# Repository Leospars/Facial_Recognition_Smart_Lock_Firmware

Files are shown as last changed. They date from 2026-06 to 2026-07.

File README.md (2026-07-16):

# JUPY Security Lock — Firmware

This repository contains the ESP32 firmware for a Facial Recognition door lock which integrates with a K230D vision module and the JUPY Locks React Native app (separate repo). The firmware manages local PIN entry, face unlock via the K230D, notifications via Firebase Cloud Messaging (FCM), and remote control via MQTT.

**Key Features**

- Face unlock integration: wakes and reads K230D UART JSON responses.
- Local passcode entry via a small TFT touchscreen keypad.
- Doorbell and remote unlock using MQTT and FCM notifications.
- On-device settings via a local REST API and secure pin-based auth.
- Battery monitoring and power-saving modes for long-life operation.

**Hardware & Pins**

- Hardware Schematic at [JUPY Lock Firmware.kicad_sch](./jupy_lock_schematic.kicad_sch)
- ESP32 (WROOM-series)
- K230D power: `K230D_PWR_PIN`
- PIR motion sensor: `PIR_PIN`
- Lock (solenoid) control: `LOCK_PIN`
- Battery ADC: `BATTERY_PIN`
- TFT / Touch pins: configured for included `TFT_eSPI` usage; see `src/main.cpp` for mapping (`TFT_MISO`, `TFT_MOSI`, `TFT_SCLK`, `TFT_CS`, `TFT_DC`).

Pin constants are defined at the top of `src/main.cpp`.

Dependencies (PlatformIO)

- Arduino Framework for ESP32
- WiFi, WiFiClientSecure
- PubSubClient (MQTT)
- ArduinoJson
- Preferences (for persistent settings)
- TFT_eSPI (display + touch)

### Setup

**Build and Flash**

1. Install PlatformIO in VS Code.
2. Open this project.
3. Configure `platformio.ini` for your board and upload.

**Configure TFT_eSPI**

Navigate to the dependency folder .pio/[board]/User_Setup.h uncomment your board and edit the following; optionally in User_Setup_Select.h select your board

```c++
// Example for ESP32 S3 Setup
// For ESP32 Dev board (only tested with ILI9341 display)
// The hardware SPI can be mapped to any pins

#define TFT_MISO 37
#define TFT_MOSI 35
#define TFT_SCLK 36
#define TFT_CS   39  // Chip select control pin
#define TFT_DC   38  // Data Command control pin
//#define TFT_RST   4  // Reset pin (could connect to RST pin)
#define TFT_RST  -1  // Set TFT_RST to -1 if display RESET is connected to ESP32 board RST
```

### Operation

**Configuration & Provisioning**

- Settings and secrets are stored in the ESP32 `Preferences` namespace (`my-settings`).
- On first boot (no saved Wi‑Fi), a BLE / Matter-style provisioning payload is expected to supply `wifi-ssid`, `wifi-pwd`, `user-id`, `lock-name`, and `owner-name`. In the example code a placeholder payload is used — replace with your BLE/Matter provisioning flow.
- Set your FCM server key in the `fcm_key` constant to enable push notifications.

**Network & Cloud Interfaces**

- MQTT broker: default `broker.hivemq.com` (change in `src/main.cpp`).
- MQTT topics used:
  - Subscribe: `lock/commands/<USER_ID>` — receives JSON commands (e.g. `{ "cmd": "unlock" }`).
  - Publish (logs): `lock/logs/<USER_ID>` (when MQTT session active).
- FCM notifications: posts to `fcm.googleapis.com` using the configured server key. Payloads send notifications to topic `/topics/<USER_ID>/all`.

**Local REST API (HTTP on ESP32)**

- `POST /unlock` — Body: JSON { "pin": "1234", "name": "Caller" }. Verifies stored PIN and pulses the lock.
- `PATCH /update-settings` — Body: JSON with `name`, `pin`, and `settings` object. Requires auth with correct owner name + PIN. Settings include: `vid-quality`,  `call-timeout`, `snippet-time`, `share-analytics`.

**Behavior Notes**

- K230D wake: PIR or remote commands call `wakeK230D()` which toggles the K230D power pin and logs activity. K230D is auto-powered down after ~3s of no face detection (configurable in code).
- Initailization: BLE server for wifi commissioning and lock setup
- Auth lockout: 3 failed auth attempts set an authorization timeout (`AUTH_DISABLE_TIME`) — after that period authFail resets.
- Intruder handling: repeated unknown-face detections increment an `intruder` counter and can cause a longer timeout.
- Battery monitoring: periodic ADC reads map to battery percentages and trigger FCM notifications for low battery states.

**Power Saving**

- Wi‑Fi modem sleep is enabled via `esp_wifi_set_ps(WIFI_PS_MIN_MODEM)` and station listen interval is adjusted to reduce power consumption.
- BLE is disabled after provisioning to save power.
- MQTT is disable during inactivity and re-enables after timeout
- Assign deep sleep wake up triggers

**Customizing & Extending**

- Replace the placeholder provisioning with Matter or your BLE service to provision Wi‑Fi and owner details.
- Replace `fcm_key` and `mqtt_server` with your production credentials.
- Adjust pin constants and voltage divider math in `monitorBattery()` to match your hardware.

**Security and Privacy**

- Use external rest api to trigger fcm to avoid committing `fcm_key` to public repos.
- Ensure MQTT broker is configured with TLS/auth if used in production.
- Consider setting up HTTPS/TLS 3.1 for local rest api in production.
- Use cryptographic keys and methods for authorizing commands and changing settings in production.

### Known Issues

- The footprint of the ESP32-S3 module is slightly smaller than the actual device in the [schematic file](./jupy_lock_schematic.kicad_sch). A perfboard was used instead to connect the pins with dupont jumper wires. 

### Future Implementations

- Encypt ble server uuid and name for qr code scan
- Implement reset lock when on board button is held for set time 3s

### Project Images

- Breadboard Assembly
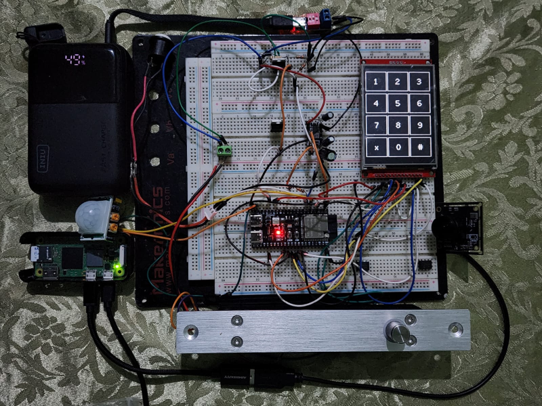
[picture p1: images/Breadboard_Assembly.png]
Breadboard Assembly Image


- Enclosed Door Lock
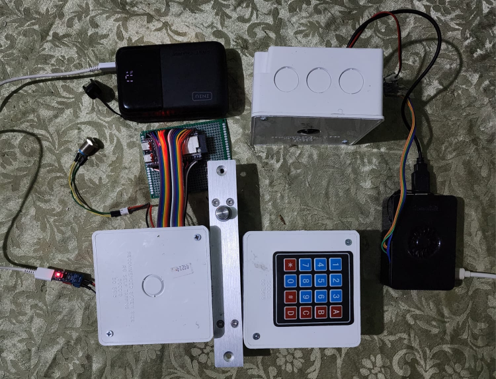
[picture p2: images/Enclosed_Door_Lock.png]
Enclosed Door Lock Image


- Proposed 3D Model
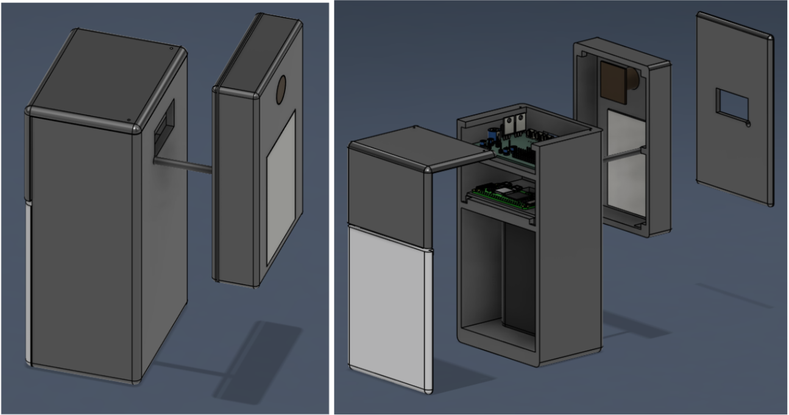
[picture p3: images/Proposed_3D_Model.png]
Proposed 3D Model Image


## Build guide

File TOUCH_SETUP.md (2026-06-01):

# Touch Screen Setup Guide

This guide explains how to set up and configure the touch screen functionality for the JUPY Smart Lock project.

## Hardware Requirements

- ILI9341 TFT Display with XPT2046 Touch Controller
- ESP32-S3 Development Board
- Proper wiring connections as per the schematic

## Pin Configuration

The touch screen uses the following pins (defined in `include/User_Setup.h`):

- **TOUCH_CS**: GPIO 40 - Touch controller chip select
- **T_IRQ**: GPIO 21 - Touch interrupt pin
- **TFT SPI Pins**:
  - MOSI: GPIO 11
  - MISO: GPIO 13
  - SCLK: GPIO 12
  - TFT_CS: GPIO 10
  - TFT_DC: GPIO 9
  - TFT_RST: -1 (connected to ESP32 RST)

## Software Configuration

### 1. Library Dependencies

The following libraries are required and configured in `platformio.ini`:

- `bodmer/TFT_eSPI@^2.5.43` - TFT display library
- `paulstoffregen/XPT2046_Touchscreen@^1.4.0` - Touch controller library

### 2. TFT_eSPI Configuration

A custom `User_Setup.h` file is provided in the `include/` directory with the correct pin configuration for ESP32-S3 and ILI9341 display.

Key settings:
- Driver: `ILI9341_DRIVER`
- SPI Frequency: 27MHz for display, 2.5MHz for touch
- Touch enabled with TOUCH_CS and T_IRQ pins

### 3. Touch Calibration

The touch screen requires calibration to map touch coordinates to display coordinates.

#### Automatic Calibration
- Uncomment `// touch_calibrate();` in `setup()` function
- Upload and run the code
- Follow on-screen instructions to touch the corners
- Calibration data will be printed to Serial monitor
- Copy the calibration array and update the code

#### Manual Calibration Data
Default calibration data is provided:
```cpp
uint16_t calData[5] = {1, 65024, 8, 64506, 5};
tft.setTouch(calData);
```

## Code Integration

### Touch Handling

The touch functionality is implemented in the `handleTouch()` function:

- Detects touch state changes
- Maps touch coordinates to keypad grid (4x3 layout)
- Processes key presses through `processKeyPress()`

### Keypad Layout

The touch screen implements a 4x3 keypad:
```
1 2 3
4 5 6
7 8 9
x 0 #
```

Where:
- `x`: Clear
- `0`: Number 0
- `#`: Enter/Submit

## Troubleshooting

### Common Issues

1. **Ghost Touches / (0,0) Coordinates**
   - Check TOUCH_CS pin connection
   - Verify T_IRQ pin connection
   - Ensure stable 3.3V power to touch controller
   - Check for SPI bus conflicts

2. **Inconsistent Touch Response**
   - Reduce SPI frequency in User_Setup.h
   - Check for electrical noise
   - Verify touch panel is properly seated

3. **Wrong Coordinates**
   - Run touch calibration
   - Update calibration data in code
   - Check display rotation setting

### Diagnostic Steps

1. Run the `touch_diagnostic.ino` sketch from the `tests/` directory
2. Check Serial output for touch events
3. Verify pin connections with multimeter
4. Test SPI communication

### Hardware Checks

- **Connections**: Ensure all SPI lines and control pins are securely connected
- **Power**: Verify 3.3V supply to touch controller
- **Ground**: Check for proper ground connections
- **Damage**: Inspect touch overlay for physical damage

## Testing

After setup:

1. Upload the code to ESP32-S3
2. Open Serial monitor
3. Touch the screen and observe coordinate output
4. Test keypad functionality by touching number areas
5. Verify PIN entry works

## References

- [TFT_eSPI Library Documentation](https://github.com/Bodmer/TFT_eSPI)
- [XPT2046 Touchscreen Library](https://github.com/PaulStoffregen/XPT2046_Touchscreen)
- [ILI9341 + XPT2046 Troubleshooting Guide](./tests/touch_troubleshooting_guide.md)

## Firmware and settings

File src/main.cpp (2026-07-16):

#include <Arduino.h>
#include <ArduinoJson.h>
#include <FastLED.h>
#include <HTTPClient.h>
#include <Preferences.h>
#include <PubSubClient.h>
#include <SPI.h>
#include <TFT_eSPI.h>
#include <WebServer.h>
#include <WiFi.h>
#include <WiFiClientSecure.h>
#include <esp_sntp.h>
#include <esp_wifi.h>
#include <time.h>

#include "ble_server.h"
#include "esp_bt.h"
#include <Keypad.h>

// --- Pins (As specified) ---
#define LOCK_PIN 7
#define SBC_PWR_PIN 8
#define BATTERY_PIN 6
#define PIR_PIN 4
#define BUTTON_PIN 5
#define T_IRQ 21        // Touch Interrupt
#define TFT_LED 13      // TFT Backlight
#define RGB_LED_PIN 48  // RGB LED data pin for ESP32-S3 DevKitM
#define NUM_LEDS 1
#define BRIGHTNESS 40
CRGB leds[NUM_LEDS];

// Display PINS initialized in User_Setup.h of TFT_eSPI Library

// --- Configuration & Credentials ---
#define LOCK_ID "c0ffee01-1234-4abc-9def-9876543210aa"  // Unique Lock Identifier UUIDv7
#define SIMPLE_ID "coff"                                // Simple ID (first 4 characters of LOCK_ID)
#define LOCK_MODEL "JUPY Lock Pro"                      // Lock Model
#define FIRMWARE_VERSION "v1.0"                         // Firmware version
#define PAIRING_CODE "123456"                           // Lock Pairing Code
#define RESET_PIN "01455489"               // Reset PIN for factory reset/delete lock via REST API/touch pad
#define BACKUP_PIN "01455489"              // Dynamic Backup PIN that changes after use via REST API
#define AUTH_DISABLE_TIME 30 * 60000UL     // 30 minutes
#define BATT_CHECK_TIMEOUT 5 * 60000ULL    // 5 minutes
#define COMMISSION_TIME 10 * 60000UL       // 10 minutes
#define MQTT_ACTIVE_TIMEOUT 2 * 60000UL    // 2 minutes
#define SBC_POWEROFF_DELAY 2000UL          // 2s grace period for Pi cleanup before GPIO LOW
#define SBC_MAX_RUNTIME 6 * 1000UL         // 6s max runtime for SBC before auto power-off
#define MAX_NOTIF 10                       // Max notifications to store offline
#define DEF_NOTIF_NAME "Manual Operation"  // Default notification name

// --- Remote MQTT (HiveMQ Cloud) ---
const char *mqtt_server = "72300a81dfec465f840ffafaa812a8bb.s1.eu.hivemq.cloud";
const char *mqtt_user = "jupyLock";
const char *mqtt_pwd = "jupyLock012";

// --- Local MQTT broker (Raspberry Pi 5 / jupy_bridge.local) ---
// Uses same credentials as HiveMQ for consistency (Mosquitto configured with password auth)
const char *local_mqtt_host = "jupy-bridge.local";
const uint16_t local_mqtt_port = 1883;
const char *local_mqtt_user = "jupyLock";
const char *local_mqtt_pwd = "jupyLock012";

// --- Local MQTT Topics ---
// ESP32 → Pi
#define TOPIC_SBC_CMD                                                                                                  \
  "jupy/sbc/cmd"  // Commands to SBC: on, capture_face, doorbell_chime, start_call, update_settings, commission,
                  // power_off
#define TOPIC_SETTINGS "jupy/settings"  // Full settings JSON push → Pi writes to settings.json
// Pi → ESP32
#define TOPIC_SBC_STATUS "jupy/sbc/status"  // Status responses from SBC: match, intruder, no_face, awake, error, etc.

// --- Supabase ---
const char *projectId = "ienqcmbfdobzcggkhajc";
const String api_base_endpoint = "https://" + String(projectId) + ".supabase.co/functions/v1/make-server-a213de84";
// ("http://" + String(laptop_ip) + ":3000/api/lock/register").c_str(); //local dev
const String analytics_endpoint = api_base_endpoint + "/analytics";
const String notification_endpoint = api_base_endpoint + "/event/" + LOCK_ID;
const String register_lock_endpoint = api_base_endpoint + "/locks/register";
const String lock_endpoint = api_base_endpoint + "/lock/" + LOCK_ID;

String touchpad_keys[4][3] = {
    {"1", "2", "3"}, {"4", "5", "6"}, {"7", "8", "9"}, {"x", "0", "#"}  // X: Clear, B: Bell/Enter
};

// Keypad configuration
const byte ROWS = 4;
const byte COLS = 4;
char keypad_keys[ROWS][COLS] = {{'1', '2', '3', ' '}, {'4', '5', '6', ' '}, {'7', '8', '9', ' '}, {'x', '0', '#', ' '}};
byte rowPins[ROWS] = {13, 12, 11, 10};
byte colPins[COLS] = {18, 17, 16, 15};
// Remapped pinout for telephone style-membrane switch 3x4 Keypad {C1, C2, C3, C4, R1, R2, R3, R4}=>{C2, R1, C1, R4, C3,
// R3, R2}
// byte rowPins[ROWS] = {16, 12, 11, 18};
// byte colPins[COLS] = {17, 15, 10};

Keypad keypad = Keypad(makeKeymap(keypad_keys), rowPins, colPins, ROWS, COLS);

/****** root certificate (for HiveMQ TLS) *********/
static const char *root_ca PROGMEM = R"EOF(
-----BEGIN CERTIFICATE-----
MIIFazCCA1OgAwIBAgIRAIIQz7DSQONZRGPgu2OCiwAwDQYJKoZIhvcNAQELBQAw
TzELMAkGA1UEBhMCVVMxKTAnBgNVBAoTIEludGVybmV0IFNlY3VyaXR5IFJlc2Vh
cmNoIEdyb3VwMRUwEwYDVQQDEwxJU1JHIFJvb3QgWDEwHhcNMTUwNjA0MTEwNDM4
WhcNMzUwNjA0MTEwNDM4WjBPMQswCQYDVQQGEwJVUzEpMCcGA1UEChMgSW50ZXJu
ZXQgU2VjdXJpdHkgUmVzZWFyY2ggR3JvdXAxFTATBgNVBAMTDElTUkcgUm9vdCBY
MTCCAiIwDQYJKoZIhvcNAQEBBQADggIPADCCAgoCggIBAK3oJHP0FDfzm54rVygc
h77ct984kIxuPOZXoHj3dcKi/vVqbvYATyjb3miGbESTtrFj/RQSa78f0uoxmyF+
0TM8ukj13Xnfs7j/EvEhmkvBioZxaUpmZmyPfjxwv60pIgbz5MDmgK7iS4+3mX6U
A5/TR5d8mUgjU+g4rk8Kb4Mu0UlXjIB0ttov0DiNewNwIRt18jA8+o+u3dpjq+sW
T8KOEUt+zwvo/7V3LvSye0rgTBIlDHCNAymg4VMk7BPZ7hm/ELNKjD+Jo2FR3qyH
B5T0Y3HsLuJvW5iB4YlcNHlsdu87kGJ55tukmi8mxdAQ4Q7e2RCOFvu396j3x+UC
B5iPNgiV5+I3lg02dZ77DnKxHZu8A/lJBdiB3QW0KtZB6awBdpUKD9jf1b0SHzUv
KBds0pjBqAlkd25HN7rOrFleaJ1/ctaJxQZBKT5ZPt0m9STJEadao0xAH0ahmbWn
OlFuhjuefXKnEgV4We0+UXgVCwOPjdAvBbI+e0ocS3MFEvzG6uBQE3xDk3SzynTn
jh8BCNAw1FtxNrQHusEwMFxIt4I7mKZ9YIqioymCzLq9gwQbooMDQaHWBfEbwrbw
qHyGO0aoSCqI3Haadr8faqU9GY/rOPNk3sgrDQoo//fb4hVC1CLQJ13hef4Y53CI
rU7m2Ys6xt0nUW7/vGT1M0NPAgMBAAGjQjBAMA4GA1UdDwEB/wQEAwIBBjAPBgNV
HRMBAf8EBTADAQH/MB0GA1UdDgQWBBR5tFnme7bl5AFzgAiIyBpY9umbbjANBgkq
hkiG9w0BAQsFAAOCAgEAVR9YqbyyqFDQDLHYGmkgJykIrGF1XIpu+ILlaS/V9lZL
ubhzEFnTIZd+50xx+7LSYK05qAvqFyFWhfFQDlnrzuBZ6brJFe+GnY+EgPbk6ZGQ
3BebYhtF8GaV0nxvwuo77x/Py9auJ/GpsMiu/X1+mvoiBOv/2X/qkSsisRcOj/KK
NFtY2PwByVS5uCbMiogziUwthDyC3+6WVwW6LLv3xLfHTjuCvjHIInNzktHCgKQ5
ORAzI4JMPJ+GslWYHb4phowim57iaztXOoJwTdwJx4nLCgdNbOhdjsnvzqvHu7Ur
TkXWStAmzOVyyghqpZXjFaH3pO3JLF+l+/+sKAIuvtd7u+Nxe5AW0wdeRlN8NwdC
jNPElpzVmbUq4JUagEiuTDkHzsxHpFKVK7q4+63SM1N95R1NbdWhscdCb+ZAJzVc
oyi3B43njTOQ5yOf+1CceWxG1bQVs5ZufpsMljq4Ui0/1lvh+wjChP4kqKOJ2qxq
4RgqsahDYVvTH9w7jXbyLeiNdd8XM2w9U/t7y0Ff/9yi0GE44Za4rF2LN9d11TPA
mRGunUHBcnWEvgJBQl9nJEiU0Zsnvgc/ubhPgXRR4Xq37Z0j4r7g1SgEEzwxA57d
emyPxgcYxn/eR44/KJ4EBs+lVDR3veyJm+kXQ99b21/+jh5Xos1AnX5iItreGCc=
-----END CERTIFICATE-----
)EOF";

// --- Client Instances ---
TFT_eSPI tft = TFT_eSPI();

// Remote MQTT (HiveMQ Cloud) — TLS, for app commands and online presence
WiFiClientSecure espClient;
PubSubClient mqttClient(espClient);

// Local MQTT (Mosquitto on Pi) — plaintext, for SBC command/response
WiFiClient localEspClient;
PubSubClient localMqttClient(localEspClient);

WebServer localServer(80);
Preferences prefs;
BLECommissioningServer bleServer;

// --- Stored Variables ---
String LOCK_NAME = "";
String OWNER_NAME = "";
String USER_ID = "";
String REFRESH_TOKEN = "";

boolean FORCED_RESET_LOCK = false;  // Warning: Changing this to true will erase all user data

// --- State Management ---
unsigned long authTimeout = 0;
unsigned long bootTime = 0;
unsigned long commissionTimeout = 0;
unsigned long faceUnlockTimeout = 0;
unsigned long lastActivity = 0;
unsigned long sbcStartTime = 0;
unsigned long sbcUpTime = 0;
unsigned long lastBatCheck = 0;
unsigned long sbcPowerOffAt = 0;  // Non-zero = GPIO power-off pending after grace delay
std::vector<unsigned long> touchFadeTime(12, 0);

std::vector<int> lastTouchX(12, -1);
std::vector<int> lastTouchY(12, -1);
std::vector<int> lastTouchColor(12, TFT_BLACK);
uint8_t unlockAttempts = 0;

bool mqttActive = false;
bool localMqttConnected = false;
unsigned long lastLocalMqttRetry = 0;
unsigned long lastMqttRetry = 0;
bool sbcIsRunning = false;
bool longSBCActivity = false;
bool pinManuallyEntered = false;
bool share_analytics = false;
bool notify_all_motion = false;
bool sending_pending_notif = false;

uint8_t pendingNotificationsCount = 0;
uint8_t head = 0;
uint8_t tail = 0;
uint8_t intruder = 0;
uint8_t authFail = 0;
String passcodeBuffer = "";
std::array<String[3], 10> pendingNotifications;

// Function Prototypes
void handlePIR();
void handleTouch();
void handleKeypad();
void processKeyPress(int row, int col, int x, int y);
void handleTimeouts();
void monitorBattery(const bool startupCheck = false);
void initialCommissioning();
void connectToWifi(const String &ssid, const String &password);
void sendToSBC(String command);
void SBCPowerOff();
void reconnectLocalMQTT();
void localMqttCallback(char *topic, byte *payload, unsigned int length);
void handleLocalMqttMsg(const String &status, JsonDocument &doc);

bool checkPin(const char *);
void touch_calibrate();
void unlockDoor(String, String);
void drawKeypad();
void notify(String, String, String name = DEF_NOTIF_NAME);
void setupREST();
bool setupPin();
void serverLog(String, String);
void setOnline(bool);
void mqttCallback(char *, byte *, unsigned int);
void reconnectMQTT();
void startMQTTSession();
void endMQTTSession();
String getCurrentTimestamp();
void startSleepMode(unsigned long milli_sec = 0);

struct HTTPResponse {
  int code;
  const char *contentType;
  String body;
};

HTTPResponse handleApiRequest(const String &endpoint, String body, String token = "", HTTPMethod method = HTTP_POST);

void wakeUpReason() {
  esp_sleep_wakeup_cause_t wakeup_reason = esp_sleep_get_wakeup_cause();
  if (wakeup_reason == ESP_SLEEP_WAKEUP_EXT1) {
    Serial.println("Woke up from PIR or Button!");
  } else if (wakeup_reason == ESP_SLEEP_WAKEUP_EXT0) {
    Serial.println("Woke up from Touch!");
  } else if (wakeup_reason == ESP_SLEEP_WAKEUP_TIMER) {
    Serial.println("Woke up from Timer!");
  } else {
    Serial.println("Natural first wakeup. Not waking from deep sleep");
  }
}

CRGB DEF_LED_COLOR = CRGB::Red;
CRGB CURRENT_LED_COLOR = DEF_LED_COLOR;
CRGB KEY_PRESSED_COLOR = CRGB::Green;

void setLEDColor(uint8_t r, uint8_t g, uint8_t b) {
  leds[0] = CRGB(r, g, b);
  FastLED.show();
  CURRENT_LED_COLOR = CRGB(r, g, b);
}

void setLEDColor(CRGB color) {
  leds[0] = color;
  FastLED.show();
  CURRENT_LED_COLOR = color;
}

void resetLEDColor() {
  CURRENT_LED_COLOR = DEF_LED_COLOR;
  setLEDColor(CURRENT_LED_COLOR);
}

void setup() {
  Serial.begin(115200);
  wakeUpReason();

  // Configure screen
  Serial.println("TFT Calibrating ...");
  pinMode(TFT_CS, OUTPUT);
  pinMode(TOUCH_CS, OUTPUT);
  pinMode(T_IRQ, INPUT_PULLUP);
  pinMode(TFT_LED, OUTPUT);
  digitalWrite(TFT_CS, HIGH);
  digitalWrite(TOUCH_CS, HIGH);
  digitalWrite(TFT_LED, HIGH);

  tft.init();
  tft.setRotation(0);
  uint16_t calData[5] = {309, 3472, 357, 3449, 4};
  tft.setTouch(calData);

  pinMode(PIR_PIN, INPUT_PULLDOWN);
  pinMode(LOCK_PIN, OUTPUT);
  pinMode(SBC_PWR_PIN, OUTPUT);
  pinMode(BATTERY_PIN, INPUT_PULLDOWN);
  pinMode(BUTTON_PIN, INPUT_PULLUP);
  FastLED.addLeds<NEOPIXEL, RGB_LED_PIN>(leds, NUM_LEDS);
  FastLED.setBrightness(BRIGHTNESS);

  digitalWrite(LOCK_PIN, LOW);  // Fail-secure: LOW keeps locked
  digitalWrite(SBC_PWR_PIN, LOW);

  setLEDColor(CRGB::Lavender);

  Serial.println("Booting up... Turning on SBC & Unlock for 2 seconds");
  digitalWrite(SBC_PWR_PIN, HIGH);
  delay(2000);
  digitalWrite(SBC_PWR_PIN, LOW);
  digitalWrite(LOCK_PIN, HIGH);
  delay(2000);
  digitalWrite(LOCK_PIN, LOW);

  Serial.print("Touch CS pin: " + String(TOUCH_CS));
  Serial.printf("TFT SPI Frequency: %d Hz\n", SPI_FREQUENCY);
  Serial.printf("TFT SPI PINS: MISO: %d, MOSI: %d, SCLK: %d, CS: %d, DC: %d, RST: %d, T_CS: %d, T_IRQ: %d\n", TFT_MISO,
                TFT_MOSI, TFT_SCLK, TFT_CS, TFT_DC, TFT_RST, TOUCH_CS, T_IRQ);

  // 0. Initialize Storage
  prefs.begin("my_storage", false);
  prefs.putString("pairing_code", PAIRING_CODE);
  prefs.putString("refresh_token", "refresh_token");
  Serial.println("Stored pin: " + prefs.getString("pin"));
  notify_all_motion = prefs.getBool("notify_all_motion", notify_all_motion);
  share_analytics = prefs.getBool("share_analytics", share_analytics);

  if (prefs.getString("settings").isEmpty()) {
    JsonDocument defaultSettings;
    defaultSettings["cam_resolution"] = 1024;
    defaultSettings["call_timeout"] = 40;
    defaultSettings["snippet_time"] = 15;
    defaultSettings["record_motion"] = true;
    defaultSettings["record_person"] = true;
    defaultSettings["notify_all_motion"] = notify_all_motion;
    defaultSettings["share_analytics"] = share_analytics;
    String defaultSettingsStr;
    serializeJson(defaultSettings, defaultSettingsStr);
    prefs.putString("settings", defaultSettingsStr);
  }

  // 1. BLE Provisioning & Transition
  Serial.println("Check for commissioning");
  initialCommissioning();

  // 2. Local REST API
  Serial.println("Setup Rest Server");
  setupREST();

  // 3. SNTP, Battery, RESET mode
  monitorBattery();
  configTime(0, 0, "pool.ntp.org");

  FORCED_RESET_LOCK = prefs.getBool("forced_reset", false);
  if (FORCED_RESET_LOCK) {
    Serial.println("Awaiting reset complete from user... MQTT will remain disabled.");
    return;
  }

  // 4. Remote MQTT (HiveMQ)
  espClient.setCACert(root_ca);
  mqttClient.setServer(mqtt_server, 8883);
  mqttClient.setCallback(mqttCallback);
  mqttClient.setBufferSize(1024);
  if (WiFi.status() == WL_CONNECTED) {
    mqttActive = true;
    reconnectMQTT();
  }

  // 5. Local MQTT (Mosquitto on SBC)
  localMqttClient.setServer(local_mqtt_host, local_mqtt_port);
  localMqttClient.setCallback(localMqttCallback);
  localMqttClient.setBufferSize(1024);
  if (WiFi.status() == WL_CONNECTED) {
    reconnectLocalMQTT();

    String sbcCmd = prefs.getString("commission_cmd", "");
    if (sbcCmd.isEmpty()) {
      Serial.println("No pending SBC commission command." + sbcCmd);
    } else {
      Serial.println("Pending SBC commission command: " + sbcCmd);
    }
    for (uint8_t i = 1; i <= 10; i++) {
      if (sbcCmd.isEmpty()) break;
      if (!sendToSBC(sbcCmd)) reconnectLocalMQTT();
      else break;
      delay(1000 * i);
    }
    if (!sbcCmd.isEmpty()) {
      Serial.println("[MQTT] Failed to commission SBC after 10 attempts.");
      notify("Error", "Failed to commission SBC after 10 attempts.");
      startSleepMode();
    }
  }

  Serial.print("Device Setup Complete. ");
  Serial.println(getCurrentTimestamp());
  drawKeypad();
  Serial.println("===========================\n");
  resetLEDColor();
}

void loop() {
  handleTimeouts();

  if (digitalRead(BUTTON_PIN) == LOW) {
    unlockDoor("Manual Operation", "Button");
  }

  handlePIR();
  handleKeypad();
  handleTouch();

  // Fade touch feedback
  if (!touchFadeTime.empty() && millis() > touchFadeTime.front()) {
    if (lastTouchX.front() != -1 && lastTouchY.front() != -1) {
      tft.fillCircle(lastTouchX.front(), lastTouchY.front(), 5, lastTouchColor.front());
    }

    // Shift all fade times and touch coordinates left, unshift first element
    touchFadeTime.erase(touchFadeTime.begin());
    lastTouchX.erase(lastTouchX.begin());
    lastTouchY.erase(lastTouchY.begin());
    lastTouchColor.erase(lastTouchColor.begin());
  }

  monitorBattery();
  localServer.handleClient();

  // Remote MQTT loop
  if (mqttActive) {
    if (!mqttClient.connected()) {
      reconnectMQTT();
    }
    mqttClient.loop();
  }

  // Local MQTT loop — always attempt to stay connected when WiFi is up
  if (WiFi.status() == WL_CONNECTED) {
    if (!localMqttClient.connected()) {
      reconnectLocalMQTT();
    }
    localMqttClient.loop();
  }

  // Deferred GPIO power-off: fire after grace delay so Pi can finish cleanup
  if (sbcPowerOffAt > 0 && millis() >= sbcPowerOffAt) {
    sbcPowerOffAt = 0;
    digitalWrite(SBC_PWR_PIN, LOW);
    Serial.println("[SBC] GPIO power rail LOW (deferred).");
  }
}

// --- CORE LOGIC FUNCTIONS ---

void handlePIR() {
  if (digitalRead(PIR_PIN) == HIGH && !sbcIsRunning) {
    delay(50);  // Debounce
    Serial.println("[PIR] Motion Detected! Waking up Vision System...");
    startMQTTSession();
    sendToSBC("{\"cmd\":\"on\"}");
  }
}

void sendToSBC(String command) {
  // Power on the Pi GPIO rail (still used for hardware power control)
  digitalWrite(SBC_PWR_PIN, HIGH);

  // Augment command with face_timeout if relevant
  if (faceUnlockTimeout) {
    command.replace("}", ", \"face_timeout\":true }");
  }

  sbcStartTime = millis();
  sbcIsRunning = true;

  if (localMqttClient.connected()) {
    bool ok = localMqttClient.publish(TOPIC_SBC_CMD, command.c_str());
    Serial.printf("[LOCAL MQTT] → %s : %s [%s]\n", TOPIC_SBC_CMD, command.c_str(), ok ? "ok" : "FAIL TO SEND");
  } else {
    // Broker not reachable — log and attempt reconnect next loop tick
    Serial.printf("[LOCAL MQTT] Not connected. Dropping SBC command: %s\n", command.c_str());
    serverLog("sbc_cmd_dropped", "{\"cmd\":" + command + "}");
  }
}

// SBCPowerOff: sends power_off command to Pi for cleanup, then schedules
// GPIO LOW after SBC_POWEROFF_DELAY ms to give the Pi time to respond.
void SBCPowerOff() {
  if (localMqttClient.connected()) {
    String offCmd = "{\"cmd\":\"power_off\", \"uptime\":" + String(sbcUpTime / 1000) + "}";
    localMqttClient.publish(TOPIC_SBC_CMD, offCmd.c_str());
    Serial.println("[LOCAL MQTT] → power_off command sent to SBC.");
  }

  // Schedule GPIO LOW after grace period
  sbcPowerOffAt = millis() + SBC_POWEROFF_DELAY;

  sbcIsRunning = false;
  longSBCActivity = false;
  serverLog("sbc_power_off", "{\"uptime\":\"" + String(sbcUpTime / 1000) + "\"}");
  sbcUpTime = 0;
  Serial.println("[SBC] Power-off scheduled (GPIO LOW in " + String(SBC_POWEROFF_DELAY) + "ms).");
}

// localMqttCallback: called by PubSubClient when a message arrives on a subscribed local topic.
// This is the direct replacement for handleUART() — same status branch logic, no behavioral changes.
void localMqttCallback(char *topic, byte *payload, unsigned int length) {
  byte buffer[length + 1];
  memcpy(buffer, payload, length);
  buffer[length] = '\0';

  String topicStr = String(topic);
  Serial.printf("[LOCAL MQTT] ← %s : %s\n", topic, (char *)buffer);

  JsonDocument doc;
  DeserializationError error = deserializeJson(doc, buffer);
  if (error) {
    Serial.printf("[LOCAL MQTT] JSON parse error on topic %s: %s\n", topic, error.c_str());
    return;
  }

  if (topicStr == TOPIC_SBC_STATUS) {
    handleLocalMqttMsg(doc["status"].as<String>(), doc);
  }
}

String sanitizeJsonToString(const String msg) {
  String cleaned = msg;
  if (cleaned.isEmpty()) return msg;
  cleaned.replace("\n", "\\n");
  cleaned.replace("\r", "\\r");
  cleaned.replace("\"", "\\\"");
  if (cleaned.isEmpty()) return "\"\"";
  return cleaned;
}

// handleLocalMqttMsg: extracted from the old handleUART() body — unchanged logic.
void handleLocalMqttMsg(const String &status, JsonDocument &doc) {
  lastActivity = millis();

  if (status == "match") {
    unlockDoor(doc["name"], "Face");
    String name = doc["name"].as<String>();
    notify("Lock Status", "Unlocked by " + name + " (Face)", doc["name"].as<String>());
    serverLog("unlock", "{\"method\":\"face\", \"success\":\"true\", \"name\":\"" + doc["name"].as<String>() + "\"}");
    SBCPowerOff();

  } else if (status == "intruder") {
    notify("Intruder Alert!", "Unknown face detected at door.");
    serverLog("unlock", "{\"method\":\"face\", \"success\":\"false\"}");
    intruder += 1;
    if (intruder <= 3) {
      sbcUpTime += millis() - sbcStartTime;
      sbcStartTime = millis();
    } else {
      faceUnlockTimeout = millis();
      SBCPowerOff();
    }
  } else if (status == "no_face") {
    Serial.println("[SBC] No face detected.");
    if (notify_all_motion) notify("Motion Detected", "Motion detected but no face found.");
  } else if (status == "awake") {
    bootTime = (millis() - sbcStartTime);
    serverLog("boot", "{\"bootTime\":\"" + String(float(bootTime) / 1000.0, 4) + "\"}");
  } else if (status == "call_active" || status == "long_task_active") {
    longSBCActivity = true;
    sbcIsRunning = true;
  } else if (status == "call_ended" || status == "long_task_ended") {
    longSBCActivity = false;
    SBCPowerOff();
  } else if (status == "call_log") {
    String log;
    serializeJson(doc["log"].as<JsonArray>(), log);
    serverLog("call",
              "{\"call_duration\":" + String(doc["call_duration"].as<int>()) + ",\"call_log\":\"" + log + "\"}");
  } else if (status == "error") {
    String error = doc["error"].as<String>();
    if (error.equals("0")) {
      Serial.println("[SBC] Received generic success code. Last command executed/stopped successfully.");
      return;
    }
    error = sanitizeJsonToString(error);
    notify("SBC Error", error, "SBC");
    serverLog("sbc_error", "{\"error\":\"" + error + "\"}");
    longSBCActivity = false;
  } else if (status == "commission_success") {
    if (bleServer.isConnected()) {
      bleServer.sendResponse("{\"status\": \"commission_success\"}");
    }
    String sbcIp = doc["sbc_ip_address"].as<String>();
    String sbcHostname = doc["sbc_hostname"].as<String>();
    if (sbcIp.isEmpty() || sbcHostname.isEmpty()) {
      Serial.println("[SBC] Commission received but IP or hostname is empty.");
      return;
    }
    String payload = "{\"sbc_ip_address\":\"" + doc["sbc_ip_address"].as<String>() + "\",\"sbc_hostname\":\"" +
                     doc["sbc_hostname"].as<String>() + "\"}";
    HTTPResponse response = handleApiRequest(lock_endpoint, payload.c_str(), "", HTTP_PATCH);
    if (response.code == 200) {
      Serial.println("[SBC] SBC info updated to backend successfully.");
      prefs.putString("commission_cmd", "");
      Serial.println("[SBC] Commissioning SBC successful!");
    } else {
      Serial.printf("[SBC] Failed to update SBC info to backend. Response code: %d\n", response.code);
    }
  } else {
    Serial.println("[SBC] Unknown status: " + status);
  }
}
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

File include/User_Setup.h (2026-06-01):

//                            USER DEFINED SETTINGS
//   Set driver type, fonts to be loaded, pins used and SPI control method etc.
//
//   See the User_Setup_Select.h file if you wish to be able to define multiple
//   setups and then easily select which setup file is used by the compiler.
//
//   If this file is edited correctly then all the library example sketches should
//   run without the need to make any more changes for a particular hardware setup!
//   Note that some sketches are designed for a particular TFT pixel width/height

// User defined information reported by "Read_User_Setup" test & diagnostics example
#define USER_SETUP_INFO "User_Setup"

// Define to disable all #warnings in library (can be put in User_Setup_Select.h)
//#define DISABLE_ALL_LIBRARY_WARNINGS

// ##################################################################################
//
// Section 1. Call up the right driver file and any options for it
//
// ##################################################################################

// Define STM32 to invoke optimised processor support (only for STM32)
//#define STM32

// Defining the STM32 board allows the library to optimise the performance
// for UNO compatible "MCUfriend" style shields
//#define NUCLEO_64_TFT
//#define NUCLEO_144_TFT

// STM32 8-bit parallel only:
// If STN32 Port A or B pins 0-7 are used for 8-bit parallel data bus bits 0-7
// then this will improve rendering performance by a factor of ~8x
//#define STM_PORTA_DATA_BUS
//#define STM_PORTB_DATA_BUS

// Tell the library to use parallel mode (otherwise SPI is assumed)
//#define TFT_PARALLEL_8_BIT
//#defined TFT_PARALLEL_16_BIT // **** 16-bit parallel ONLY for RP2040 processor ****

// Display type -  only define if RPi display
//#define RPI_DISPLAY_TYPE // 20MHz maximum SPI

// Only define one driver, the other ones must be commented out
#define ILI9341_DRIVER       // Generic driver for common displays
//#define ILI9341_2_DRIVER     // Alternative ILI9341 driver, see https://github.com/Bodmer/TFT_eSPI/issues/1172
//#define ST7735_DRIVER      // Define additional parameters below for this display
//#define ILI9163_DRIVER     // Define additional parameters below for this display
//#define S6D02A1_DRIVER
//#define RPI_ILI9486_DRIVER // 20MHz maximum SPI
//#define HX8357D_DRIVER
//#define ILI9481_DRIVER
//#define ILI9486_DRIVER
//#define ILI9488_DRIVER     // WARNING: Do not connect ILI9488 display SDO to MISO if other devices share the SPI bus (TFT SDO does NOT tristate when CS is high)
//#define ST7789_DRIVER      // Full configuration option, define additional parameters below for this display
//#define ST7789_2_DRIVER    // Minimal configuration option, define additional parameters below for this display
//#define R61581_DRIVER
//#define RM68140_DRIVER
//#define ST7796_DRIVER
//#define SSD1351_DRIVER
//#define SSD1963_480_DRIVER
//#define SSD1963_800_DRIVER
//#define SSD1963_800ALT_DRIVER
//#define ILI9225_DRIVER
//#define GC9A01_DRIVER

// Some displays support SPI reads via the MISO pin, other displays have a single
// bi-directional SDA pin and the library will try to read this via the MOSI line.
// To use the SDA line for reading data from the TFT uncomment the following line:

// #define TFT_SDA_READ      // This option is for ESP32 ONLY, tested with ST7789 and GC9A01 display only

// For ST7735, ST7789 and ILI9341 ONLY, define the colour order IF the blue and red are swapped on your display
// Try ONE option at a time to find the correct colour order for your display

//  #define TFT_RGB_ORDER TFT_RGB  // Colour order Red-Green-Blue
//  #define TFT_RGB_ORDER TFT_BGR  // Colour order Blue-Green-Red

// For M5Stack ESP32 module with integrated ILI9341 display ONLY, remove // in line below

// #define M5STACK

// For ST7789, ST7735, ILI9163 and GC9A01 ONLY, define the pixel width and height in portrait orientation
// #define TFT_WIDTH  80
// #define TFT_WIDTH  128
// #define TFT_WIDTH  172 // ST7789 172 x 320
// #define TFT_WIDTH  170 // ST7789 170 x 320
// #define TFT_WIDTH  240 // ST7789 240 x 240 and 240 x 320
// #define TFT_HEIGHT 160
// #define TFT_HEIGHT 128
// #define TFT_HEIGHT 240 // ST7789 240 x 240
// #define TFT_HEIGHT 320 // ST7789 240 x 320
// #define TFT_HEIGHT 240 // GC9A01 240 x 240

// For ST7735 ONLY, define the type of display, originally this was based on the
// colour of the tab on the screen protector film but this is not always true, so try
// out the different options below if the screen does not display graphics correctly,
// e.g. colours wrong, mirror images, or stray pixels at the edges.
// Comment out ALL BUT ONE of these options for a ST7735 display driver, save this
// this User_Setup file, then rebuild and upload the sketch to the board again:

// #define ST7735_INITB
// #define ST7735_GREENTAB
// #define ST7735_GREENTAB2
// #define ST7735_GREENTAB3
// #define ST7735_GREENTAB128    // For 128 x 128 display
// #define ST7735_GREENTAB160x80 // For 160 x 80 display (BGR, inverted, 26 offset)
// #define ST7735_ROBOTLCD       // For some RobotLCD Arduino shields (128x160, BGR, https://docs.arduino.cc/retired/getting-started-guides/TFT)
// #define ST7735_REDTAB
// #define ST7735_BLACKTAB
// #define ST7735_REDTAB160x80   // For 160 x 80 display with 24 pixel offset

// If colours are inverted (white shows as black) then uncomment one of the next
// 2 lines try both options, one of the options should correct the inversion.

// #define TFT_INVERSION_ON
// #define TFT_INVERSION_OFF


// ##################################################################################
//
// Section 2. Define the pins that are used to interface with the display here
//
// ##################################################################################

// If a backlight control signal is available then define the TFT_BL pin in Section 2
// below. The backlight will be turned ON when tft.begin() is called, but the library
// needs to know if the LEDs are ON with the pin HIGH or LOW. If the LEDs are to be
// driven with a PWM signal or turned OFF/ON then this must be handled by the user
// sketch. e.g. with digitalWrite(TFT_BL, LOW);

// #define TFT_BL   32            // LED back-light control pin
// #define TFT_BACKLIGHT_ON HIGH  // Level to turn ON back-light (HIGH or LOW)
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

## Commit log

2026-02-27 feat: Added switch to AP mode when wifi unavailable
2026-06-01 Refactor code structure for improved readability and maintainability - Lots of edits done will need to come back and seperate and re commit
    [jupy_lock_schematic.kicad_sch]
2026-06-03 feat|refactor|fix: Added LED status indetification, refactor startDeepSleep and serverLog, add macro for max sbc uptime
    - refactor: added more BLE status message report for ccommissioning and fix initialCommissioning spelling, removed emojis because of character error in JSON.
    - fix: delete endpoint require userid
    [main.cpp]
2026-06-11 chore(fcm)!: remove FCM as it was replaced with MQTT notification and is handled by Remote API
    - Note: fcm registration tokens is deprecated for installation IDs
    [main.cpp]
2026-07-16 chore: improved sleep mode with proper serial flush and wakeup pin configuration and added battery monitoring debug logging
2026-07-16 feat|fix: Enhanced SBC commissioning with better error handling and response validation and added commission command persistence for retry capability
    - Fix mqtt toggling flow: only reconnectMqtt/reconnectLocalMQTT to turn on Mqtt and handleTimeout trigger
    [main.cpp]
2026-07-16 refactor|fix: change JSON string sanitization function name and where it is used
    [main.cpp]
